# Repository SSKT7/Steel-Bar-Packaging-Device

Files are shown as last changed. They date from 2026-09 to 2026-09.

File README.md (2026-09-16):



In this project we created steel bar wrapping device for "Ette plan" . The goal of our project is to create a safe and efficient way to package large steel elements used in industrial environments. These steel elements must be protected from rain, moisture, dirt, and damage during transportation and storage

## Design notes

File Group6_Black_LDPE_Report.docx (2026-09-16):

# Black LDPE Bags for Metal Wrapping Applications

# 1. Introduction

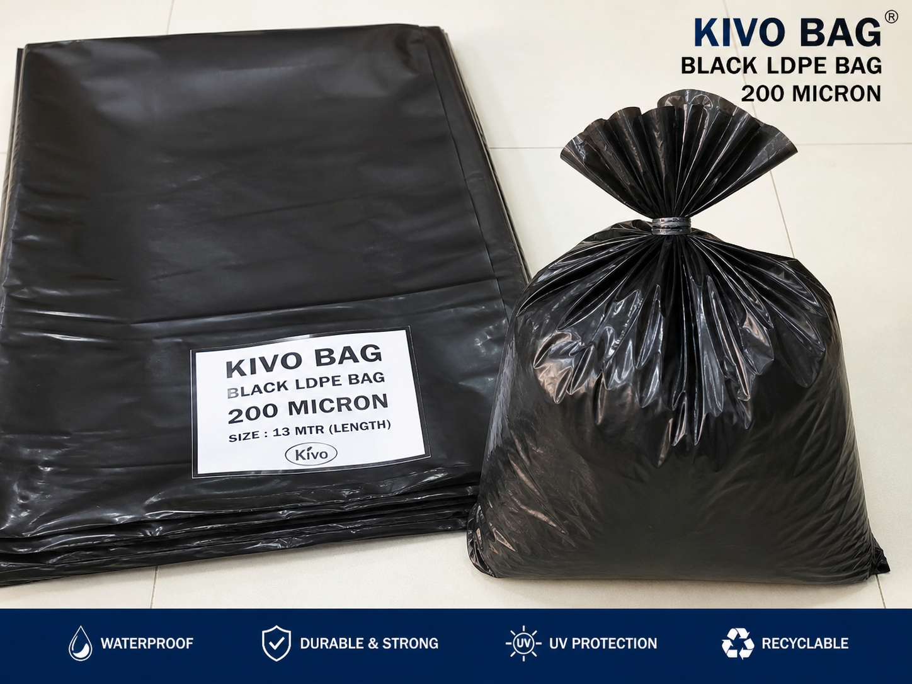
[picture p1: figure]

Picture 1 : Black LDPE bags ( taken from chatgpt)

Black Low-Density Polyethylene (LDPE) bags are widely used in industrial packaging, especially for protecting metal products during storage and transportation. These bags are known for their flexibility, durability, and resistance to moisture, making them a reliable solution for preventing environmental damage.

In metal applications such as pipes, rods, sheets, and fabricated components, black LDPE bags are often used with heat shrink methods. When heat is applied, the material shrinks and tightly conforms to the product, forming a protective outer layer. This ensures better coverage and improved protection compared to loose or manual wrapping methods.

# 2. Size Availability in the Market

Black LDPE bags are available in a wide range of sizes and specifications to meet different industrial requirements. Both standard and custom-made options are commonly offered.

Typical availability includes:

a. Thickness: 100 to 300+ microns
b. Width: From small sizes to several meters for large items
c. Length: Rolls or pre-cut bags, including long lengths such as 13 meters or more
d. Formats: Lay-flat bags, gusseted bags, and tubular rolls

This variety allows the packaging of small components as well as large and heavy metal bundles.

# 3. Advantages

Black LDPE bags provide several important benefits:

a. Moisture Protection: Acts as a barrier against water, dust, and contaminants
b. UV Resistance: Black color protects against sunlight exposure
c. Flexibility: Easily wraps around irregular shapes
d. Strength: Offers good resistance to tearing when properly handled
e. Uniform Shrink: Provides tight and even coverage when heat is applied
f. Cost-Effective: Economical compared to other packaging methods

# 4. Why It Is Effective for Wrapping Systems

Black LDPE bags are highly effective in wrapping systems due to their ability to tightly conform to the shape of the product. The heat shrink process eliminates air gaps and creates a secure, continuous protective layer.

For heavy loads, including multi-ton metal products, the bag acts as a protective covering rather than carrying weight. When combined with pallets, strapping, and edge protection, it improves load stability and reduces exposure to environmental factors.

Its ease of use and adaptability make it a preferred solution in industrial packaging.

# 5. Recycling and Environmental Considerations

LDPE is a recyclable material, which makes black LDPE bags a more sustainable option when disposed of properly.

- Can be recycled into new plastic products
- Can be reused in some cases
- Helps reduce waste when proper recycling systems are used

Recycling depends on local facilities and proper waste handling practices.

# 6. Conclusion

Black LDPE bags offer a practical, reliable, and cost-effective solution for protecting metal products. Their availability in different sizes and thicknesses allows them to meet a wide range of packaging needs.

With benefits such as moisture resistance, UV protection, and strong shrink performance, they are well suited for both transportation and storage. When used correctly, they help maintain product quality and reduce damage risks.

Overall, black LDPE bags remain a trusted and widely used packaging solution in the metal industry.

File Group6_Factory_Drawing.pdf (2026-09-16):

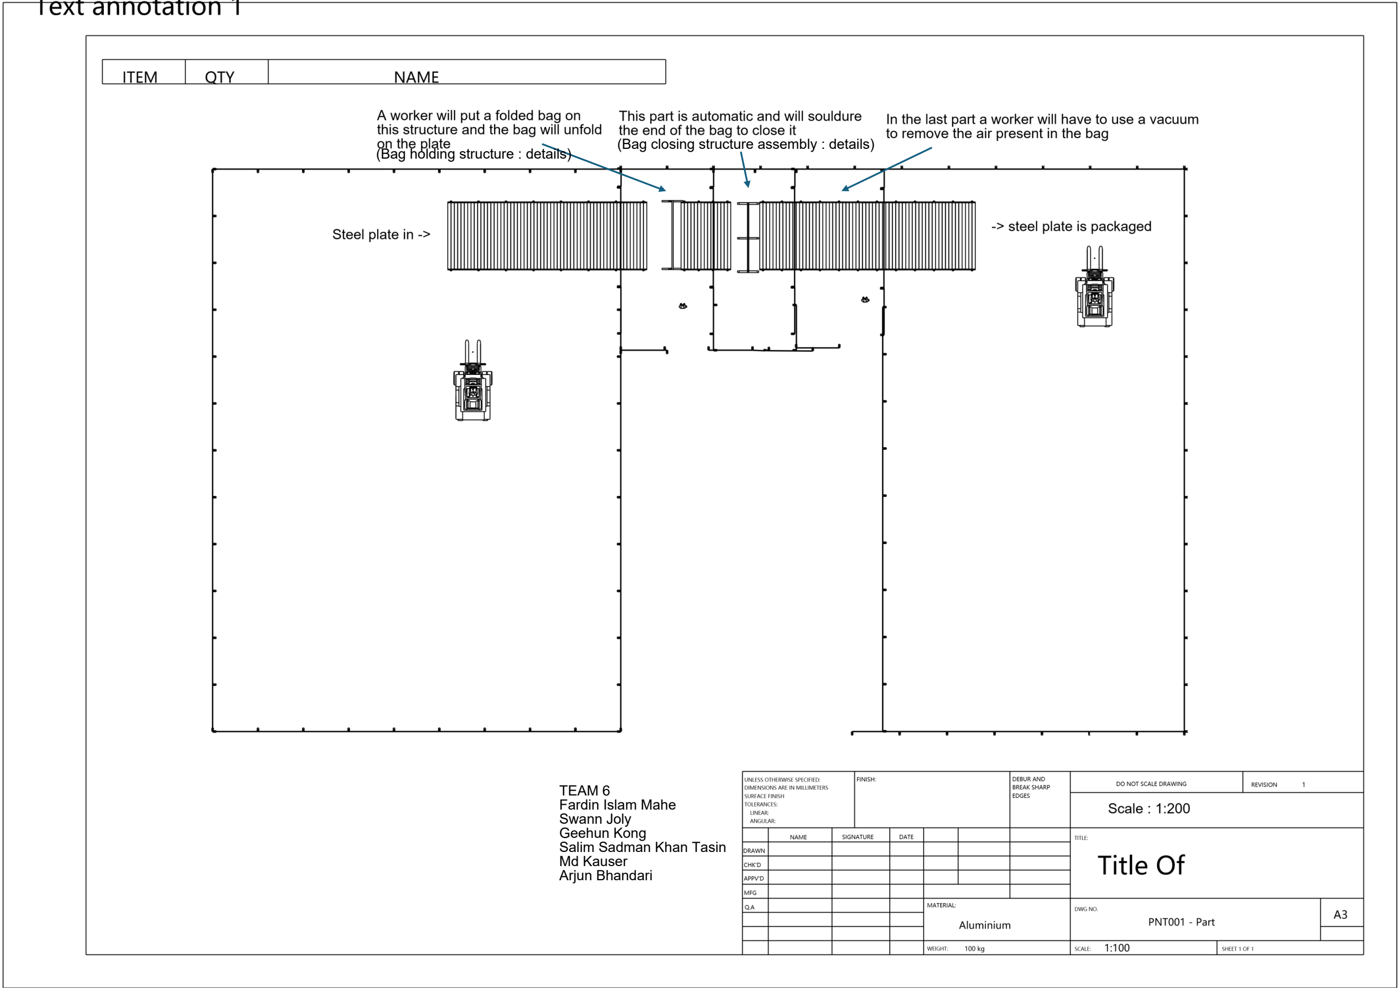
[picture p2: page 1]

TEAM 6
Fardin Islam Mahe
Swann Joly
Geehun Kong
Salim Sadman Khan Tasin
Md Kauser
Arjun Bhandari

(Bag closing structure assembly : details) (Bag holding structure : details)

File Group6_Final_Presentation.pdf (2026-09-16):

# Product design Final

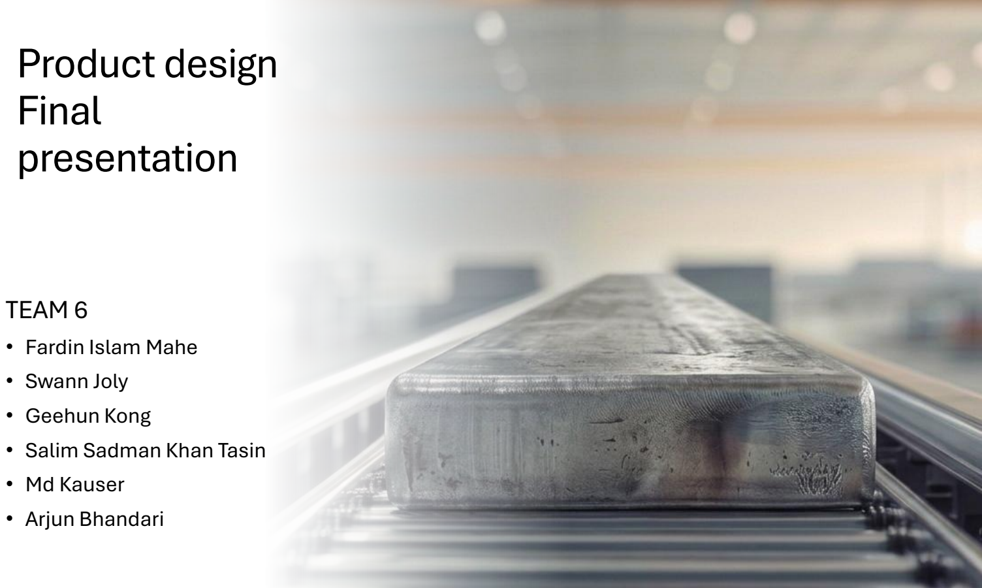
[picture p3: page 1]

# presentation

## TEAM 6

- Fardin Islam Mahe
- Swann Joly
- Geehun Kong
- Salim Sadman Khan Tasin
- Md Kauser
- Arjun Bhandari

# Design Of Steel Element Packaging

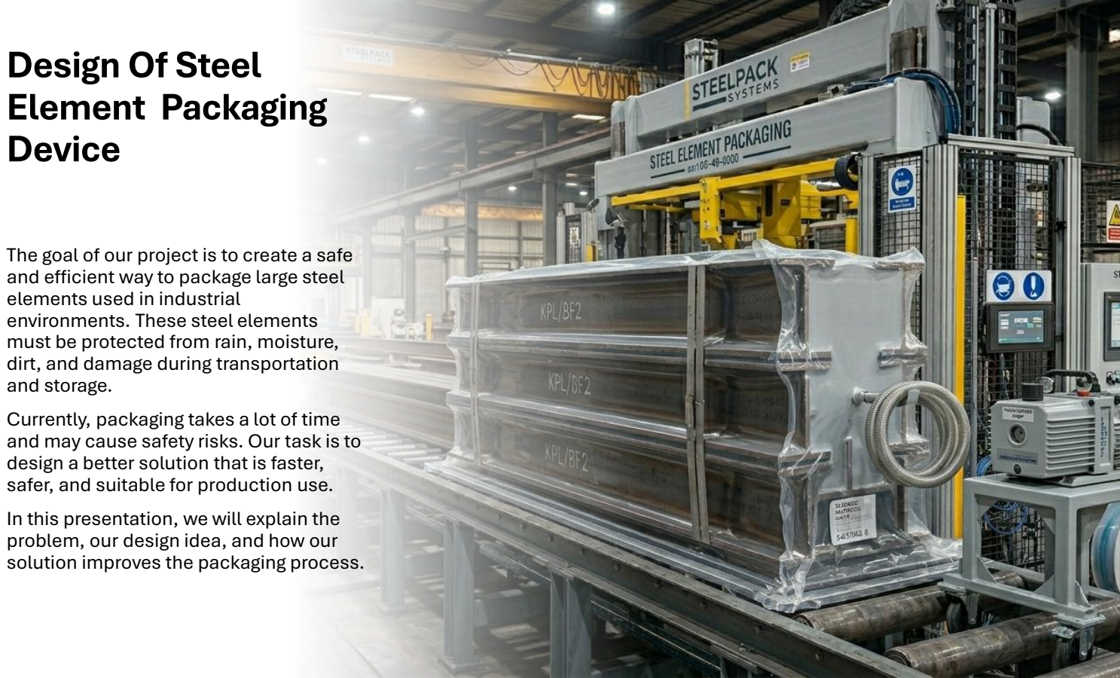
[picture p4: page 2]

# Device

The goal of our project is to create a safe and efficient way to package large steel elements used in industrial environments. These steel elements must be protected from rain, moisture, dirt, and damage during transportation and storage.
Currently, packaging takes a lot of time and may cause safety risks. Our task is to design a better solution that is faster, safer, and suitable for production use. In this presentation, we will explain the problem, our design idea, and how our solution improves the packaging process.

# Current Packaging Challenges & Current Market Solutions

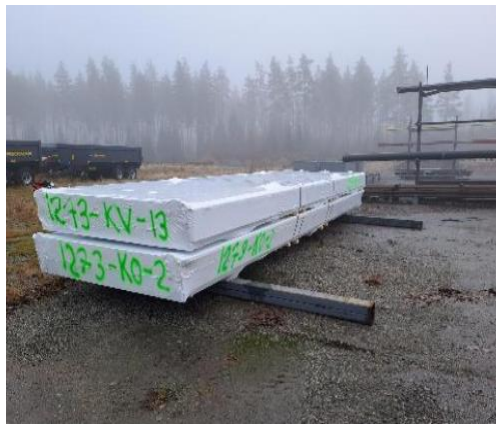
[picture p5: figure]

Existing Solution
- Manual wrapping with 8m wide shrinkwrap roll material.
- Gas flame heating used to achieve an airtight seal.
- Relatively effective for weather protection and storage.
- Conclusion: Incompatible with future serial production goals.

Safety Risks: Hazardous "hot-work" required underneath heavy elements using gas flames.
Efficiency Bottleneck: Processing time exceeds 1 hour per element, limiting throughput.
Size Complexity: Extreme variability in dimensions (up to 12m) and weights (5,000 kg).

## Challenges

# Our Solution

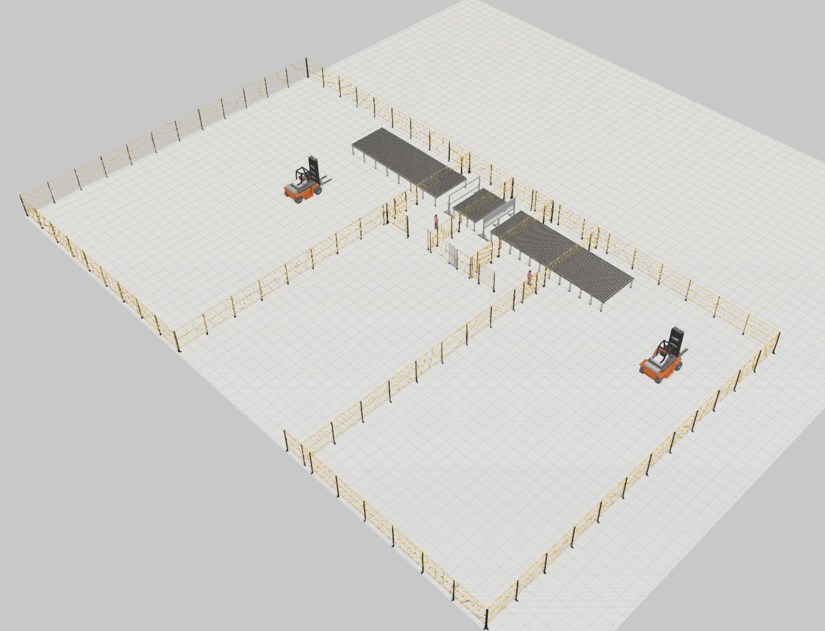
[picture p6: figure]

- An automated system designed to vacuum

-package large steel plates efficiently and safely.
- Plates are first placed onto a conveyor by a forklift and automatically transported through the system.
- A pre

-positioned bag is manually installed at the packaging station. As the plate moves forward, it enters the bag
- The system then seals the bag using a heat

-sealing bar and removes the air to create a vacuum.
- Finally, the packaged plate is conveyed to the output area, where it is collected by a forklift for storage or transport.

# Product Overview

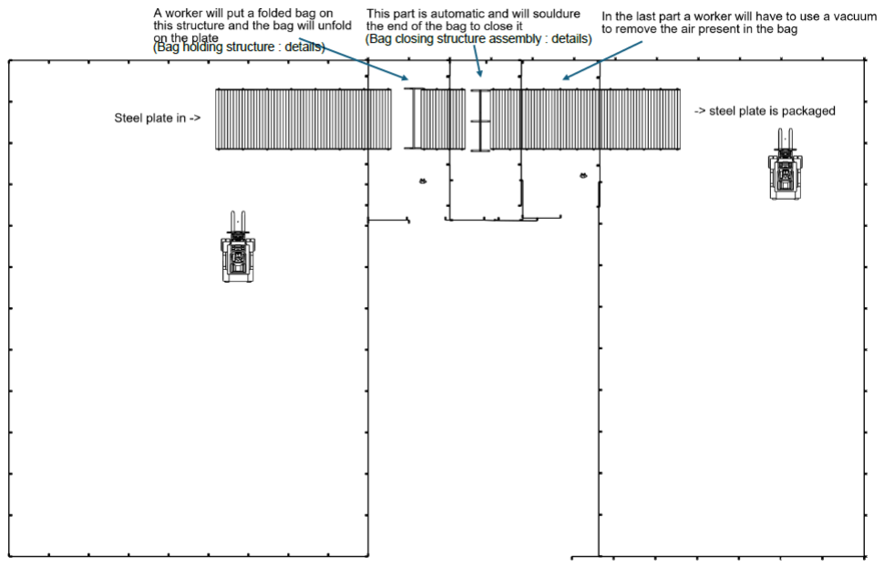
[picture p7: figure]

- Our solution will package the steel plates in 18-22
minutes depending on
the size of the plates
- The package will be
almost airtight to
avoid moisture
- The bags used will also
protect it against UV
using black bags

# Product overview

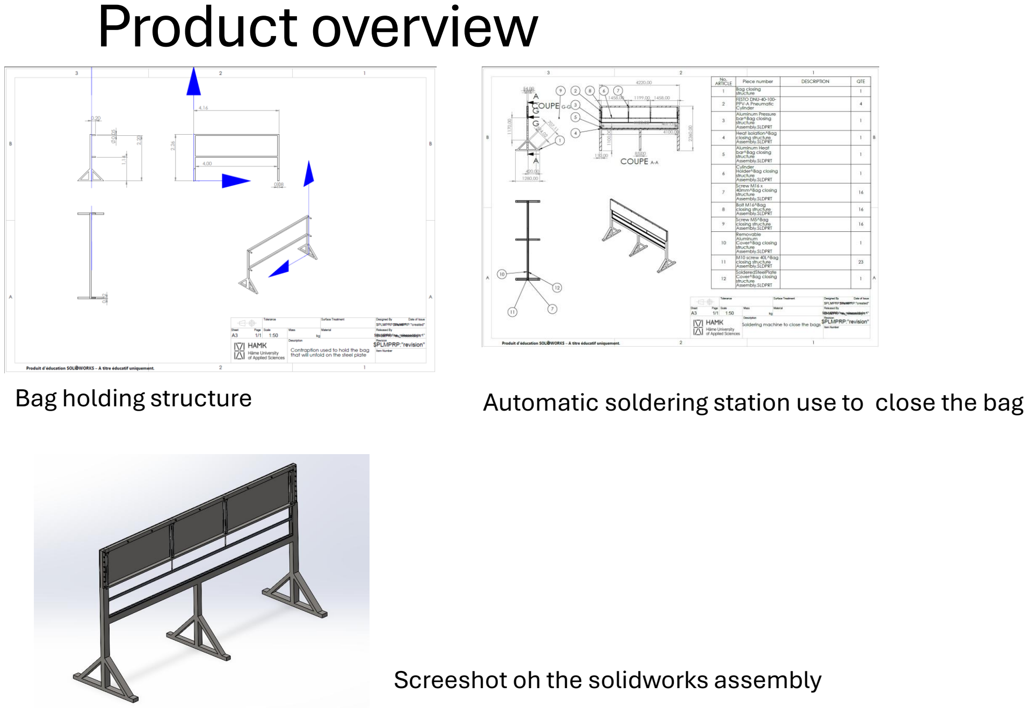
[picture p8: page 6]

Bag holding structure | Automatic soldering station use to close the bag

Screeshot oh the solidworks assembly

# Main Features

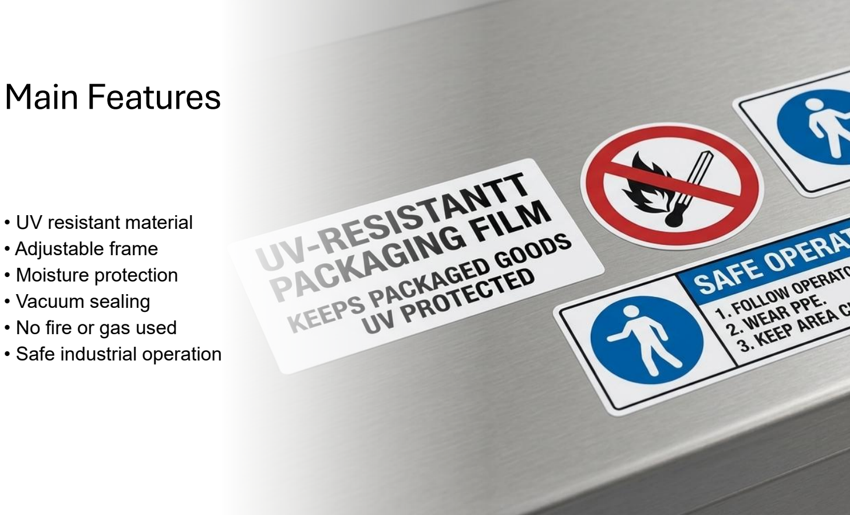
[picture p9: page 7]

- UV resistant material
- Adjustable frame
- Moisture protection
- Vacuum sealing
- No fire or gas used
- Safe industrial operation

# Risk Assessment

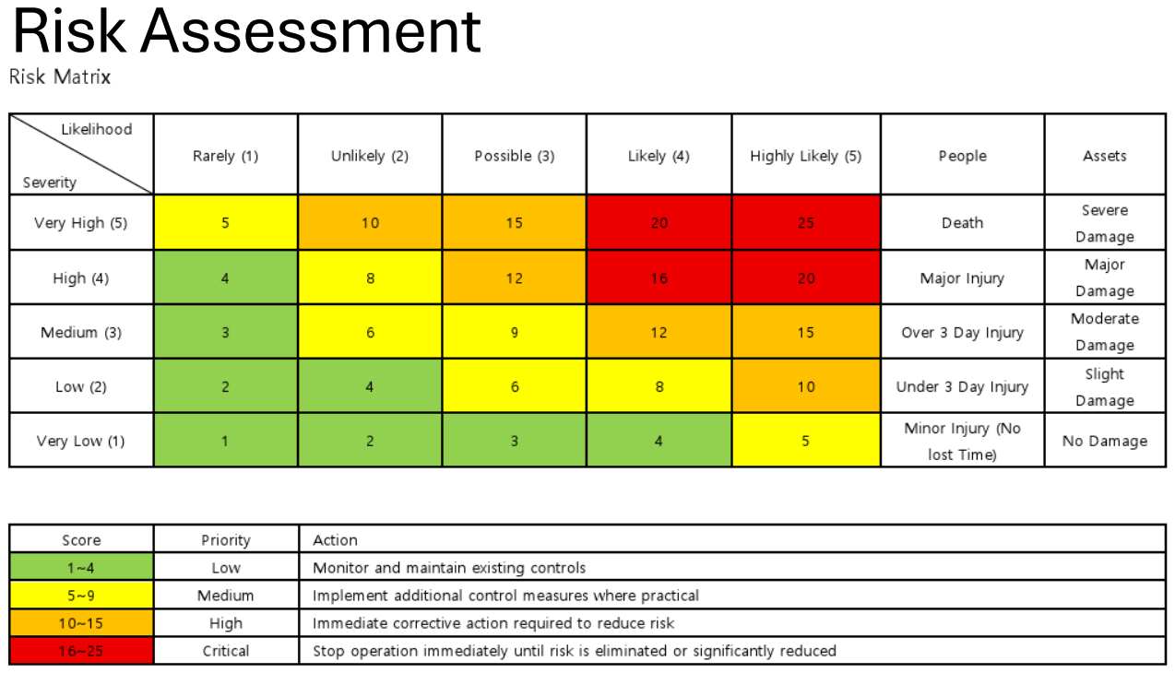
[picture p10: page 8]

# Risk Assesment

# | Hazard Identified | Risk Description | Initial | Initial Score (L x S) | Mitigations | Final | Final Score (L x S) | Responsible Team

L | S | | | L | S
1 | Forklift collision or load drop | Severe injury, Crushing, Equipment damage | 2 | 5 | 10 | Designated forklift operating zones, Proper load securing procedures, Certified operator training | 1 | 5 | 5 | Logistics Team
2 | Conveyor pinch/crush points | Hand entrapment, Crushing injury | 3 | 4 | 12 | Physical safety guards, Emergency stop systems, Restricted operator access | 1 | 4 | 4 | Mechanical Design Team
3 | Heat sealing burns | Thermal burns, Skin injury | 3 | 3 | 9 | Thermal insulation barriers, Warning Signage, Operator protective equipment | 1 | 3 | 3 | Process Design Team
4 | Vacuum sealing failure | Packaging failure, Transport instability | 3 | 2 | 6 | Routine equipment inspections, Seal quality verification, Preventive maintenance schedules | 1 | 2 | 2 | Quality Control Team
5 | Ergonomic strain | Repetitive strain, Operator fatigue | 4 | 2 | 8 | Adjustable workstation design, Task rotation, Ergonomic training | 2 | 2 | 4 | Operation Team

# Cost calculation

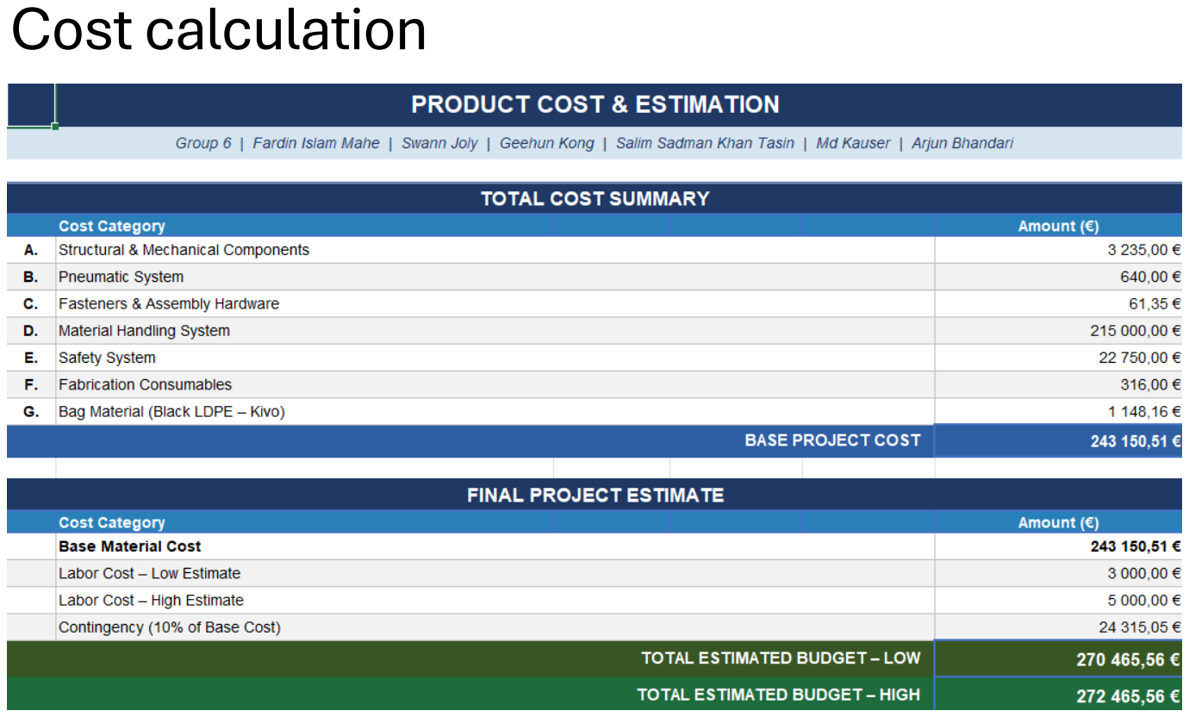
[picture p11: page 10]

## - The proposed solution significantly improves

the current manual shrink-wrapping process.

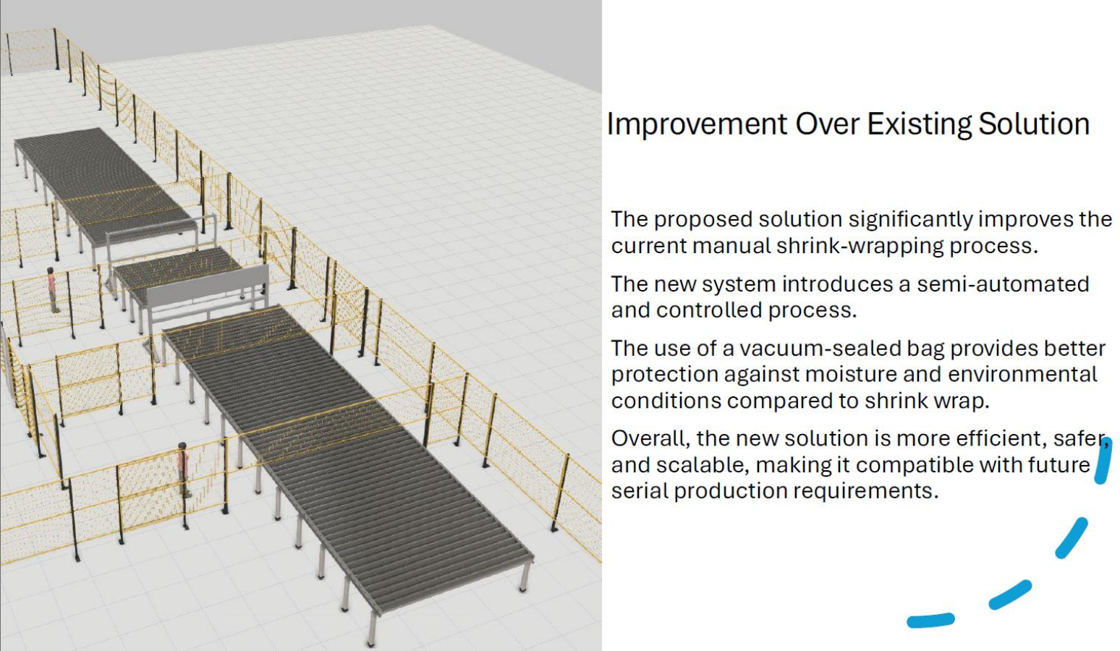
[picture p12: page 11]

# Improvement Over Existing Solution

## - The new system introduces a semi-

automated and controlled process.

## - The use of a vacuum-sealed bag provides better protection against moisture and environmental conditions compared to shrink

wrap.
- Overall, the new solution is more efficient,

## safer, and scalable, making it compatible with

future serial production requirements.

# Summary

This project focused on the design of an automated system for vacuum packaging large steel plates, ranging from 1×2 m up to 3×12 m and weighing up to 5 tons.
The proposed solution combines forklift handling with an automated conveyor system to transport the plates through different stages: positioning, bag insertion, sealing, and vacuum packaging. A prefolded bag is manually placed at the packaging station, after which the process is fully automated.
Particular attention was given to the mechanical design, including the structure, the sealing system, and the integration of pneumatic components to ensure reliable and uniform operation over large dimensions.
The system aims to reduce manual work, improve packaging consistency, and protect the plates during storage and transport. Estimated cycle times range from 10 to 20 minutes per plate, depending on size.
Overall, this project demonstrates a realistic and industrially viable solution for handling and packaging large-scale steel components.

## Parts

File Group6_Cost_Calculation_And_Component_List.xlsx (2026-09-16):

PRODUCT COST & ESTIMATION
Group 6 | Fardin Islam Mahe | Swann Joly | Geehun Kong | Salim Sadman Khan Tasin | Md Kauser | Arjun Bhandari
A. Structural & Mechanical Components
No. | Component / Description | Qty | Unit Price (€) | Total Cost (€) | Supplier
A1 | Main Structure – Steel Profiles S235 (HEA100 columns, RHS beams, angle bracing) | 400 kg | 4.00 € | 1600.00 € | Feon oy
A2 | Aluminum Pressure Bar | 1 | 160.00 € | 160.00 € | Alu-Rebel.fi
A3 | Aluminum Heat Bar | 1 | 250.00 € | 250.00 € | Alu-Rebel.fi
A4 | Heat Isolation Strip | 1 | 45.00 € | 45.00 € | Etola.fi
A5 | Cylinder Holder | 1 | 50.00 € | 50.00 € | Würth Finland
A6 | Bag Holder Contraption – Steel Frame S235 (RHS frame, tube rail, angle bracing) | 200 kg | 4.00 € | 800.00 € | Feon oy
A7 | Soldered Steel Plate Cover | 1 | 200.00 € | 200.00 € | Terästarvike.fi
A8 | Removable Aluminum Cover | 1 | 130.00 € | 130.00 € | Alu-Rebel.fi
Subtotal |  |  |  | 3235.00 €
B. Pneumatic System
No. | Component / Description | Qty | Unit Price (€) | Total Cost (€) | Supplier
B1 | Festo DNU-40-100 PPV-A Cylinder | 4 | 160.00 € | 640.00 € | ahlsell.fi
Subtotal |  |  |  | 640.00 €
C. Fasteners & Assembly Hardware
No. | Component / Description | Qty | Unit Price (€) | Total Cost (€) | Supplier
C1 | Screw M16 × 40mm | 16 | 1.80 € | 28.80 € | IKH.fi – M16×40 Bolt DIN933
C2 | Bolt M16 | 16 | 0.95 € | 15.20 € | IKH.fi – M16 Bolts & Nuts
C3 | Screw M5 | 16 | 0.15 € | 2.40 € | IKH.fi – Bolts & Nuts
C4 | M10 Screw 40L | 23 | 0.65 € | 14.95 € | IKH.fi – Bolts & Nuts
Subtotal |  |  |  | 61.35 €
D. Material Handling System
No. | Component / Description | Qty | Unit Price (€) | Total Cost (€) | Supplier
D1 | Heavy-Duty Roller Conveyor – 12m × 4m × 1.2m, ≥5t capacity (dimensions adjustable) | 2 | 25000.00 € | 50000.00 € | Ferroplan Oy
D2 | Heavy-Duty Roller Conveyor – 3m × 4m × 1.2m, ≥5t capacity (dimensions adjustable) | 1 | 5000.00 € | 5000.00 € | Ferroplan Oy
D3 | Forklift – 5t Capacity, Electric/LPG (e.g. Toyota Traigo80 counterbalanced) | 2 | 80000.00 € | 160000.00 € | Toyota Material Handling Finland
Subtotal |  |  |  | 215000.00 €
E. Safety System
No. | Component / Description | Qty | Unit Price (€) | Total Cost (€) | Supplier
E1 | Perimeter Fence (Steel Mesh & Posts) – 350 m | 350 | 65.00 € | 22750.00 € | Troax Oy
Subtotal |  |  |  | 22750.00 €
F. Fabrication Consumables
No. | Component / Description | Qty | Unit Price (€) | Total Cost (€) | Supplier
F1 | Gas | Welding Gas (Mison 18 / 20L) | 2 | 90.00 € | 180.00 € | aga.fi
F2 | Wire | Welding Wire (5 kg) | 2 | 35.00 € | 70.00 € | wurth.fi
F3 | Tools | Cutting & Grinding Discs | 30 | 2.20 € | 66.00 € | wurth.fi
Subtotal |  |  |  | 316.00 €
G. Bag Material (Black LDPE – Kivo, Finnish Market)
No. | Component / Description | Qty | Unit Price (€) | Total Cost (€) | Supplier
G1 | Black LDPE Film Bag – 0.5 m wide × 13 m long, 200 micron | Est. weight: ~1.196 kg/pc | 1 pc | 40.00 € | 47.84 € | Kivo (kivo.nl) – Finnish market rate, 40 €/kg
G2 | Black LDPE Film Bag – 1.0 m wide × 13 m long, 200 micron | Est. weight: ~2.392 kg/pc | 1 pc | 40.00 € | 95.68 € | Kivo (kivo.nl) – Finnish market rate, 40 €/kg
G3 | Black LDPE Film Bag – 1.5 m wide × 13 m long, 200 micron | Est. weight: ~3.588 kg/pc | 1 pc | 40.00 € | 143.52 € | Kivo (kivo.nl) – Finnish market rate, 40 €/kg
G4 | Black LDPE Film Bag – 2.0 m wide × 13 m long, 200 micron | Est. weight: ~4.784 kg/pc | 1 pc | 40.00 € | 191.36 € | Kivo (kivo.nl) – Finnish market rate, 40 €/kg
G5 | Black LDPE Film Bag – 3.0 m wide × 13 m long, 200 micron | Est. weight: ~7.176 kg/pc | 1 pc | 40.00 € | 287.04 € | Kivo (kivo.nl) – Finnish market rate, 40 €/kg
G6 | Black LDPE Film Bag – 4.0 m wide × 13 m long, 200 micron | Est. weight: ~9.568 kg/pc | 1 pc | 40.00 € | 382.72 € | Kivo (kivo.nl) – Finnish market rate, 40 €/kg
Subtotal |  |  |  | 1148.16 €
TOTAL COST SUMMARY
 | Cost Category |  |  |  | Amount (€)
A. | Structural & Mechanical Components |  |  |  | 3235.00 €
B. | Pneumatic System |  |  |  | 640.00 €
C. | Fasteners & Assembly Hardware |  |  |  | 61.35 €
D. | Material Handling System |  |  |  | 215000.00 €
E. | Safety System |  |  |  | 22750.00 €
F. | Fabrication Consumables |  |  |  | 316.00 €
G. | Bag Material (Black LDPE – Kivo) |  |  |  | 1148.16 €
BASE PROJECT COST |  |  |  |  | 243150.51 €
FINAL PROJECT ESTIMATE
 | Cost Category |  |  |  | Amount (€)
 | Base Material Cost |  |  |  | 243150.51 €
 | Labor Cost – Low Estimate |  |  |  | 3000.00 €
 | Labor Cost – High Estimate |  |  |  | 5000.00 €
 | Contingency (10% of Base Cost) |  |  |  | 24315.05 €
TOTAL ESTIMATED BUDGET – LOW |  |  |  |  | 270465.56 €
TOTAL ESTIMATED BUDGET – HIGH |  |  |  |  | 272465.56 €

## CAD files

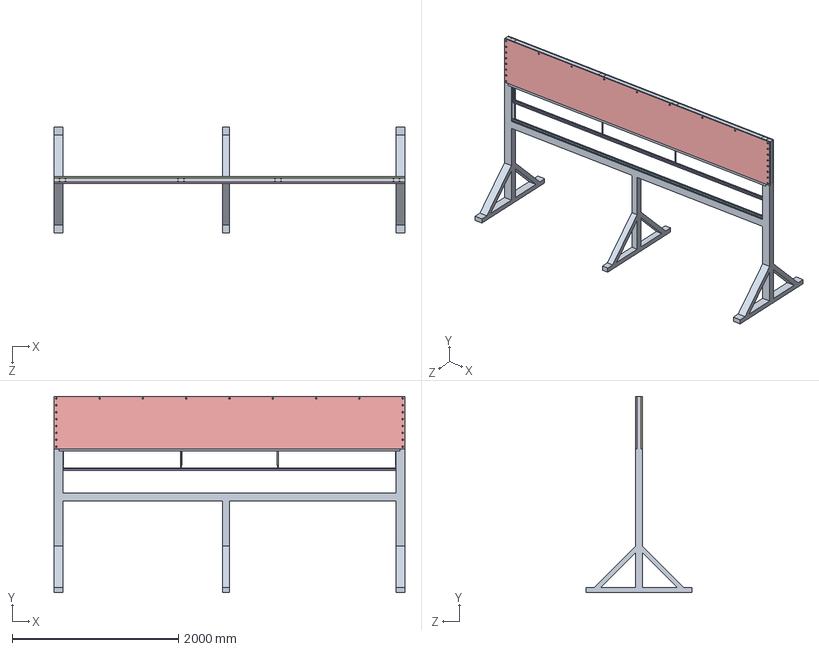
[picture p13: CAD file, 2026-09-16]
Group6_Bag_Closing_Structure_Assembly.STEP
4220.0 x 2360.0 x 1280.0 mm
Bag closing structure
DNU-40-100-ppv-a x 4
piston rod DNU-40-100-ppv-a x 4
Chape^FESTO-ISO cylinder DSBC-32-500-PPVA-N3 x 4
Aluminum Pressure bar^Bag closing structure Assembly.SLDPRT
Heat isolation^Bag closing structure Assembly.SLDPRT
Aluminum Heat bar^Bag closing structure Assembly.SLDPRT
Cylinder Holder^Bag closing structure Assembly.SLDPRT
Screw M16 x 40mm^Bag closing structure Assembly.SLDPRT x 16
Bolt M16^Bag closing structure Assembly.SLDPRT x 16
Screw M5^Bag closing structure Assembly.SLDPRT x 16
Removable Aluminum Cover^Bag closing structure Assembly.SLDPRT
M10 screw 40L^Bag closing structure Assembly.SLDPRT x 23
SolderedSteelPlateCover^Bag closing structure Assembly.SLDPRT

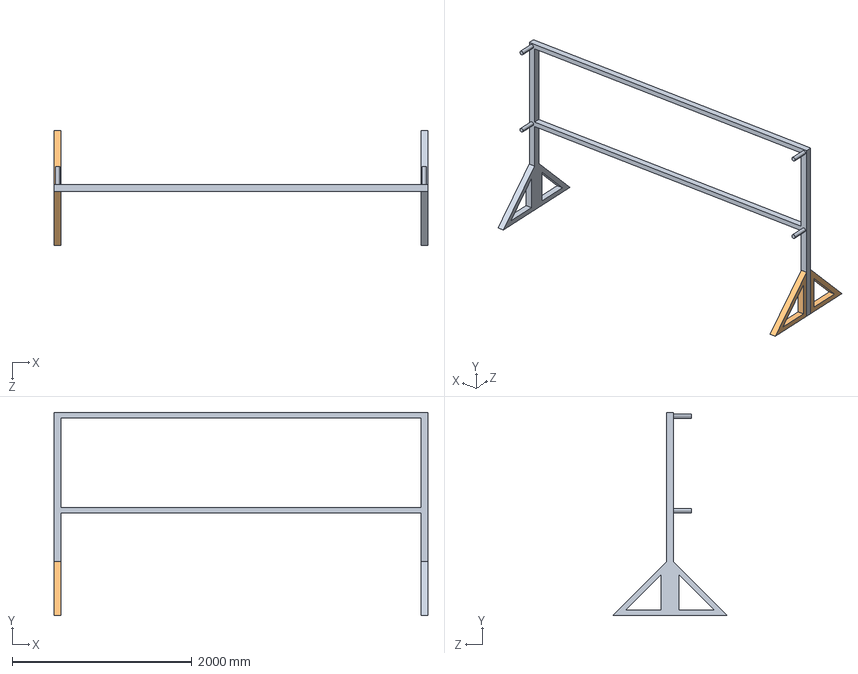
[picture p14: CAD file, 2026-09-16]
Group6_Bag_Holding_Structure.STEP
4160.0 x 2260.0 x 1280.0 mm

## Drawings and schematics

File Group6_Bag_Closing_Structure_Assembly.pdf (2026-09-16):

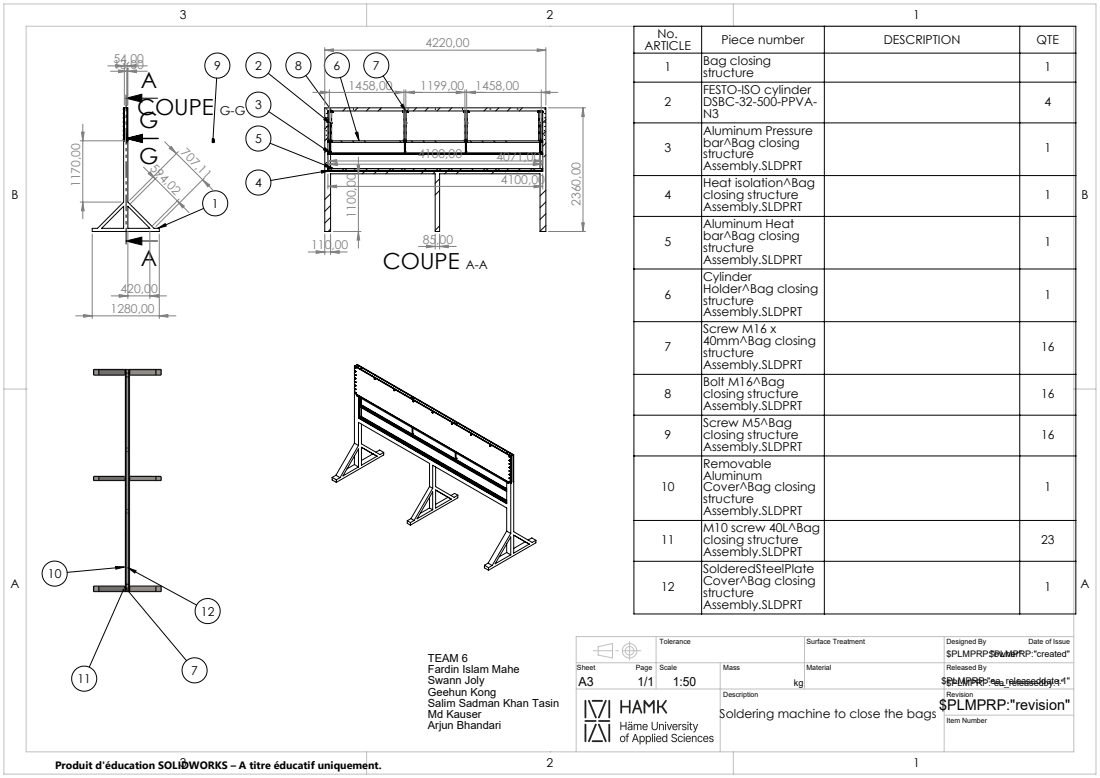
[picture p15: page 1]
COUPE A-A; COUPE G-G; Designed By; Item Number; Surface Treatment; Released By

No. ARTICLE | Piece number | DESCRIPTION | QTE
1 | Bag closing structure | | 1
2 | FESTO-ISO cylinder DSBC-32-500-PPVA-N3 | | 4

3 | Aluminum Pressure bar^Bag closing structure Assembly.SLDPRT | | 1

4 | Heat isolation^Bag closing structure Assembly.SLDPRT | | 1

5 | Aluminum Heat bar^Bag closing structure Assembly.SLDPRT | | 1

6 | Cylinder Holder^Bag closing structure Assembly.SLDPRT | | 1

7 | Screw M16 x 40mm^Bag closing structure Assembly.SLDPRT | | 16

8 | Bolt M16^Bag closing structure Assembly.SLDPRT | | 16

9 | Screw M5^Bag closing structure Assembly.SLDPRT | | 16

10 | Removable Aluminum Cover^Bag closing structure Assembly.SLDPRT | | 1

11 | M10 screw 40L^Bag closing structure Assembly.SLDPRT | | 23

12 | SolderedSteelPlate Cover^Bag closing structure Assembly.SLDPRT | | 1

Date of Issue

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

Page
Scale
$PLMPRP:"revision" Description
Soldering machine to close the bags

Produit d'éducation SOLIDWORKS – A titre éducatif uniquement.

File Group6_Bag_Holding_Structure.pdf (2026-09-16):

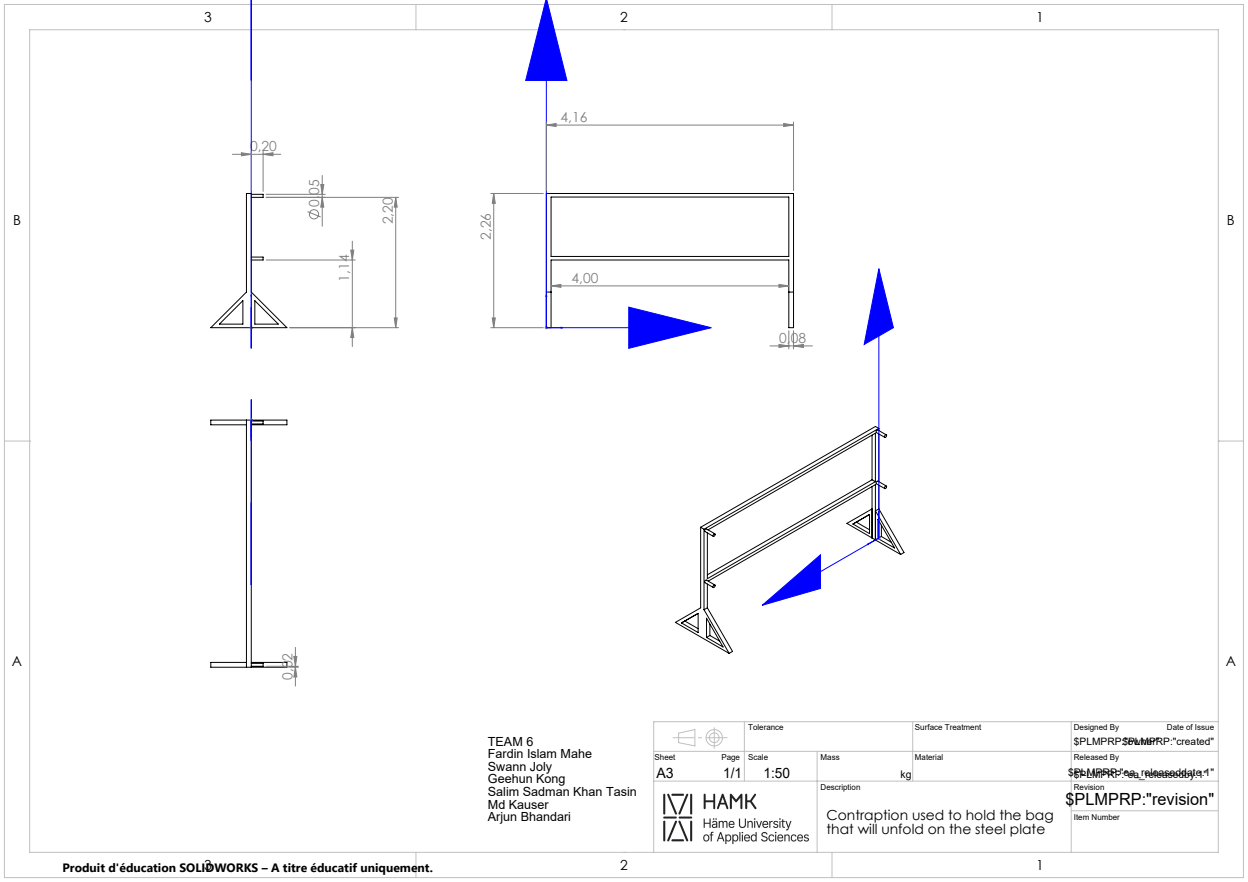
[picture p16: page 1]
Designed By; Item Number; Surface Treatment; Released By

Date of Issue

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

Page
Scale
$PLMPRP:"revision" Description
Contraption used to hold the bag
that will unfold on the steel plate

Produit d'éducation SOLIDWORKS – A titre éducatif uniquement.

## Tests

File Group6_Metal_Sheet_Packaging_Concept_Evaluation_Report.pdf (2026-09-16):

### 4 Ideas for the Packaging Process

Group 6: Geehun Kong, Swann Joly, Salim Sadman Khan Tasin, Md Kauser, Fardin Islam Mahe, Arjun Bhandari

Abstract

There are 4 ideas we came up with which are vacuum pump, orbital wrap, fabric bag with velcro, black sleeve. We are going to explain working principle of each idea and evaluate all ideas to choose the best option.

### 1. Working Principle

### 1.1 Vacuum Pump

The process begins with a forklift placing the steel plate onto the infeed conveyor. The conveyor automatically transports the plate into the packaging area. In this section, a pre-folded PA/PE bag is positioned manually by an operator. A new bag must be placed for each cycle. As the plate moves forward on the conveyor, it enters the open bag, which unfolds around it and fully encloses the part. Once the plate is completely inside the bag, it is transferred to the next conveyor section leading to the sealing station. The bag is then sealed using a heat-sealing system, and air is removed to create a vacuum. Finally, the packaged plate exits the machine on the outfeed conveyor, where a forklift picks it up and transports it to storage or shipping.

### 1.2 Orbital Wrap

First of all, the metal sheets are transported into the orbital wrapping machine using a conveyor. Then the sheet is centered and a rotating ring wraps protective film around it. Once the wrapping is completed, the sheet is automatically released for the next step.

### 1.3 Fabric Bag with Velcro

First, Metal sheets on the conveyor will be fed into the packaging machine using magnetic grippers and crane. Then the metal sheet will be placed onto the bag and automatically wrapped around using Velcro. Finally, reinforced areas are applied to each corner and protective housings are installed over the lifting lugs. We can create hole aligned with lugs in the bag.

### 1.4 Black Sleeve

The sheet element is first placed on supports and is put inside a strong black sleeve. The sleeve covers the whole product and protects it from sunlight, water, and dirt. After that, the open end of the sleeve is closed using straps or a flap. Inside the sleeve, there are small bags(desiccant bag) that absorb moisture to stop rust from forming. The sleeve is tight and strong. So it does not tear easily during transport. When the product arrives, the sleeve can be opened and removed quickly.

### 2. Evaluation Criteria

Airtight UV
Protection

Handle
Size
Variation

Safety Serial
Production

Low
Capital
Cost

No
Marks

Mean

Weight | 5 | 5 | 3 | 5 | 3 | 2 | 5 | N/A
Vacuum | 5.0/5 | 5.0/5 | 3.7/5 | 5.0/5 | 4.5/5 | 4.3/5 | 5.0/5 | 4.757
Orbital | 4.0/5 | 5.0/5 | 4.5/5 | 5.0/5 | 5.0/5 | 4.7/5 | 5.0/5 | 4.746
Fabric | 1.5/5 | 5.0/5 | 3.5/5 | 4.5/5 | 3.5/5 | 4.7/5 | 4.5/5 | 3.786
Sleeve | 2.5/5 | 5.0/5 | 4.0/5 | 4.5/5 | 3.0/5 | 4.8/5 | 4.7/5 | 4.039

We evaluated our four ideas using seven criteria (airtightness, UV protection, etc.) and assigned a weight to each criterion based on its importance.

### 2.1 Airtightness

Orbital wrapping received a slightly lower score than vacuum packaging because, although it provides strong protective wrapping, it does not create a completely sealed environment. Small air gaps or incomplete sealing may still allow limited moisture or air penetration, making it less effective for corrosion prevention than vacuum packaging. Fabric bag packaging received a significantly lower score because Velcro closures and fabric materials cannot fully isolate the product from external air or moisture. This limited sealing performance reduces protection against humidity and corrosion. Black sleeve packaging also received a relatively low score because, despite offering external coverage, it does not provide true airtight sealing. Moisture and air can still enter through openings or loose areas, making it less suitable for long-term rust prevention.

### 2.2 UV Protection

All four packaging concepts received full scores in UV protection because each design fully covers the metal sheet using protective materials that effectively block direct sunlight. Whether through vacuum film, orbital wrap, fabric covering, or black sleeve material, all solutions provide sufficient protection against UV exposure.

### 2.3 Handle Size Variation

Orbital wrapping received the highest score because its automated wrapping system can efficiently adapt to various sheet sizes with minimal structural changes. Black sleeve packaging also scored highly due to its flexible material, which can cover different dimensions relatively easily. Fabric bag packaging offered moderate adaptability, but required more customization such as Velcro fitting and lifting lug alignment, reducing flexibility. Vacuum packaging received the lowest score in this category because vacuum chambers or sealing systems often require more precise size adjustments for different products, limiting versatility.

### 2.4 Safety

Vacuum packaging and orbital wrapping both received the highest scores because their highly automated processes significantly reduce human intervention, lowering operational risks. Fabric bag and black sleeve concepts scored slightly lower because they involve more manual handling steps, such as fitting, fastening, or positioning, which can increase worker exposure to potential hazards. Although these methods are still relatively safe, reduced automation creates more opportunities for human error or handling-related accidents.

### 2.5 Serial Production

Orbital wrapping achieved the highest score because it is particularly suitable for continuous, high-speed industrial packaging operations. Vacuum packaging also performed strongly, but slightly lower due to potentially slower sealing cycles. Fabric bag and black sleeve concepts scored lower because they require more complex or slower packaging processes, reducing efficiency for large-scale serial production. Manual or semi-automated elements in these designs limit throughput compared to dedicated industrial machinery.

### 2.6 Low Capital Cost

Black sleeve and fabric bag concepts received the highest scores because they require relatively simple materials and minimal machinery, resulting in lower initial investment costs. Orbital wrapping also performed well, as although machinery is required, the system is less complex than vacuum infrastructure. Vacuum packaging received the lowest score because specialized vacuum pumps, sealing systems, and automation equipment significantly increase startup costs.

### 2.7 No Marks

Vacuum packaging and orbital wrapping both received the highest scores because they secure the product tightly, minimizing movement and reducing the risk of scratches or surface marks during transportation. Black sleeve packaging scored slightly lower because some internal movement may still occur, potentially causing friction damage. Fabric bag packaging also performed reasonably well, but fitting complexity and material movement created a slightly greater chance of surface imperfections.

### 3. The Final Idea

Although both vacuum packaging and orbital wrapping achieved similarly high evaluation scores, vacuum packaging was ultimately selected as the optimal solution. This decision was primarily based on its superior airtightness, enhanced moisture prevention, and stronger long-term preservation performance, which are critical factors for protecting sheet metal products during storage and transportation. Therefore, we decided to proceed with the vacuum idea.

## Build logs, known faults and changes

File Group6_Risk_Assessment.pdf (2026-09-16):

1 / 2

# Risk Assessment

Project | Metal sheet packaging device | Product | Vacuum based packaging system
Date | 2 May 2026
Team 6 | Geehun Kong | Fardin Islam Mahe
| Joly Swann | Arjun Bhandari
| Salim Sadman Khan Tasin | Kauser Md
Work description | The system uses conveyor automation, manual bag placement, vacuum sealing, and heat sealing to package steel plates efficiently for safe transportation and storage.

## Risk Matrix

Likelihood Severity | Rarely (1) | Unlikely (2) | Possible (3) | Likely (4) | Highly Likely (5) | People | Assets
Very High (5) | 5 | 10 | 15 | 20 | 25 | Death | Severe Damage
High (4) | 4 | 8 | 12 | 16 | 20 | Major Injury | Major Damage
Medium (3) | 3 | 6 | 9 | 12 | 15 | Over 3 Day Injury | Moderate Damage
Low (2) | 2 | 4 | 6 | 8 | 10 | Under 3 Day Injury | Slight Damage
Very Low (1) | 1 | 2 | 3 | 4 | 5 | Minor Injury (No lost Time) | No Damage
Score | Priority | Action
1~4 | Low | Monitor and maintain existing controls
5~9 | Medium | Implement additional control measures where practical
10~15 | High | Immediate corrective action required to reduce risk
16~25 | Critical | Stop operation immediately until risk is eliminated or significantly reduced
# | Hazard Identified | Risk Description | Initial | Initial Score (L x S) | Mitigations | Final | Final Score (L x S) | Responsible Team

L | S | | | L | S
1 | Forklift collision or load drop | Severe injury, Crushing, Equipment damage | 2 | 5 | 10 | Designated forklift operating zones, proper load securing procedures, and certified operator training should be implemented to minimize collision and load drop risks. | 1 | 5 | 5 | Logistics Team
2 | Conveyor pinch/crush points | Hand entrapment, Crushing injury | 3 | 4 | 12 | Physical safety guards, emergency stop systems, and restricted operator access should be installed around conveyor moving parts to prevent entrapment injuries. | 1 | 4 | 4 | Mechanical Design Team

2 / 2

# Risk Assessment

# | Hazard Identified | Risk Description | Initial | Initial Score (L x S) | Mitigations | Final | Final Score (L x S) | Responsible Team

L | S | | | L | S
3 | Sharp steel plate edges | Cuts, lacerations | 4 | 3 | 12 | Protective edge covers, mandatory PPE gloves, and safe material handling procedures should be used to reduce cutting and laceration hazards. | 2 | 2 | 4 | Safety Team
4 | Heat sealing burns | Thermal burns, Skin injury | 3 | 3 | 9 | Thermal insulation barriers, warning signage, and operator protective equipment should be provided to minimize burn injuries from hot sealing components. | 1 | 3 | 3 | Process Design Team
5 | Product jam or blockage | Mechanical overload, Unsafe intervention | 3 | 3 | 9 | Automatic shutdown sensors, jam detection systems, and lockout procedures should be applied before manual intervention to reduce overload and injury risks. | 1 | 3 | 3 | Mechanical Design Team
6 | Vacuum sealing failure | Packaging failure, Transport instability | 3 | 2 | 6 | Routine equipment inspections, seal quality verification, and preventive maintenance schedules should be maintained to ensure packaging reliability. | 1 | 2 | 2 | Quality Control Team
7 | Ergonomic strain | Repetitive strain, Operator fatigue | 4 | 2 | 8 | Adjustable workstation design, task rotation, and ergonomic training should be implemented to reduce repetitive strain and operator fatigue. | 2 | 2 | 4 | Operations Team
8 | Maintenance hazards | Burn injury, Entanglement, Accidental activation | 2 | 4 | 8 | Lockout/tagout procedures, machine power isolation, and maintenance-specific PPE should be enforced during servicing activities. | 1 | 4 | 4 | Maintenance Team

* L = Likelihood, S = Severity

* This risk assessment was conducted in accordance with SFS-EN ISO 12100:2010 principles
